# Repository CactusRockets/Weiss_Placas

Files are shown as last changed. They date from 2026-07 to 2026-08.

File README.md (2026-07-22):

# Placa de Iluminação Weiss

Placa de acionamento de iluminação desenvolvida em **KiCad**, responsável por controlar dois LEDs com o objetivo de iluminar a parte interna do weiss através de uma chave (push-button), a partir de uma alimentação externa de **3.3V**. O projeto foi desenhado para ser simples e robusto, priorizando facilidade de montagem (todos os componentes em THT) e baixo custo.

## Visão geral do circuito

O circuito é alimentado externamente via um conector **JST XH de 2 vias**, que entrega +3.3V e GND à placa. Essa alimentação passa por um **push-button (SW1)**, que atua como chave liga/desliga geral do circuito. A partir do botão, a alimentação se divide em **dois ramos em paralelo**, cada um composto por um resistor limitador de corrente em série com um LED de alta potência:

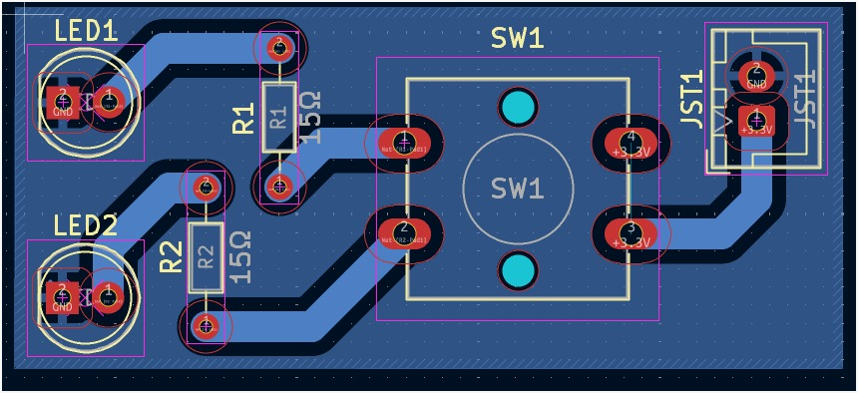
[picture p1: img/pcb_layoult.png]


Ou seja: quando o botão é pressionado (ou travado, dependendo do tipo de chave utilizada), o circuito fecha e os dois LEDs acendem simultaneamente. Cada LED possui seu próprio resistor, de forma que o brilho e a corrente de cada um são definidos de forma independente — isso evita que uma eventual diferença entre os dois LEDs (tensão direta, tolerância) afete o outro ramo, como aconteceria se estivessem em paralelo direto sob um único resistor.

Foram incluídas **PWR_FLAGs** no esquemático em +3.3V e GND. Elas não fazem parte do circuito fisicamente: servem apenas para informar ao ERC (Electrical Rules Checker) do KiCad que esses nós de alimentação são supridos por uma fonte externa (o JST), evitando falsos positivos de "net não alimentada".

## Componentes

| Referência | Componente | Footprint / Símbolo | Função |
|---|---|---|---|
| **JST1** | Conector JST XH 2 vias | `Connector_JST:JST_XH_B2B-XH-A_1x02_P2.50mm_Vertical` | Entrada de alimentação externa (+3.3V e GND) |
| **SW1** | Push-button | `Button_Switch_SMD:SW_SPST_B3S-1000` (footprint na placa: `SW_SPST_Omron_B3F-40xx-CRD`) | Chave de acionamento (liga/desliga) do circuito |
| **R1** | Resistor 15Ω | `Resistor_THT:R_Axial_DIN0204_L3.6mm_D1.6mm_P7.62mm_Horizontal` | Limitador de corrente do LED U1 |
| **R2** | Resistor 15Ω | `Resistor_THT:R_Axial_DIN0204_L3.6mm_D1.6mm_P7.62mm_Horizontal` | Limitador de corrente do LED U2 |
| **U1** | LED de alta potência | `LED_THT:LED_D5.0mm` | Iluminação (ramo 1) |
| **U2** | LED de alta potência | `LED_THT:LED_D5.0mm` | Iluminação (ramo 2) |

> Os símbolos `JST_basic`, `Push_button_4_pin` e `Led_High` são customizados e estão definidos na biblioteca local `CRD_KICAD.kicad_sym`, criada para padronizar os componentes usados nos projetos da Cactus Rockets.

## Funcionamento

O funcionamento da placa é puramente analógico/passivo — não há microcontrolador ou lógica embarcada:

1. A alimentação de +3.3V chega pelo conector **JST1**.
2. O **SW1** atua como interruptor: enquanto estiver fechado, a corrente flui para os dois ramos de LED.
3. Cada ramo (R + LED) limita a corrente que passa pelo respectivo LED, garantindo que ele opere dentro da faixa segura especificada pelo fabricante, evitando queima por excesso de corrente.
4. O retorno de ambos os ramos é feito para o **GND** comum da placa, que fecha o circuito de volta à fonte externa.

Por não haver controle ativo (PWM, microcontrolador, etc.), o brilho dos LEDs é fixo e definido unicamente pelo valor dos resistores e pela tensão de alimentação — não há dimerização nem controle remoto nesta versão da placa.

## Cálculo dos resistores limitadores

O valor do resistor limitador é definido pela equação pela lei de ohm:

```
R = (V_fonte - V_LED) / I_LED
```

Com `V_fonte = 3.3V` e `R = 15Ω`, a corrente em cada ramo depende da tensão direta (V_f) do LED utilizado. Por exemplo:

- Para um LED com V_f ≈ 2.0V → I ≈ (3.3 − 2.0) / 15 ≈ **87 mA**
- Para um LED com V_f ≈ 3.0V → I ≈ (3.3 − 3.0) / 15 ≈ **20 mA**

## Placa (PCB)

- Placa de **1.6mm** de espessura (FR4 padrão), com contorno definido em `Edge.Cuts`.
- Todos os componentes são **THT** (through-hole), facilitando a montagem manual e a soldagem.
- Footprints utilizados:
  - `CRD_Footprints:SW_SPST_Omron_B3F-40xx-CRD` (SW1)
  - `LED_THT:LED_D5.0mm` / `CRD_Footprints:LED_D5.0mm-CRD` (U1, U2)
  - `Resistor_THT:R_Axial_DIN0204_L3.6mm_D1.6mm_P7.62mm_Horizontal` (R1, R2)
  - `Connector_JST:JST_XH_B2B-XH-A_1x02_P2.50mm_Vertical` (JST1)

## Arquivos do projeto

| Arquivo | Descrição |
|---|---|
| `Placa_de_Iluminação_Weiss.kicad_sch` | Esquemático elétrico da placa |
| `Placa_de_Iluminação_Weiss.kicad_pcb` | Layout da placa (PCB) |
| `Placa_de_Iluminação_Weiss.kicad_pro` | Arquivo de projeto do KiCad |
| `CRD_KICAD.kicad_sym` | Biblioteca de símbolos customizados da Cactus Rockets |
| `fp-lib-table` | Tabela de bibliotecas de footprints usadas no projeto |

# Placa de Processamento — Weiss

Placa eletrônica central do projeto **Weiss**, desenvolvida em **KiCad**, responsável por concentrar o processamento, a aquisição de dados, o armazenamento local e as interfaces de telemetria e sinalização do sistema.

O projeto utiliza um **ESP32 DevKit V1** como controlador principal e integra módulos de rádio LoRa, GPS, cartão microSD, barômetro, unidade inercial, buzzer, LED de status e conectores para sinais externos.

> **Atenção:** esta documentação foi levantada a partir do esquemático e do layout da placa. Antes da fabricação ou da integração ao veículo, execute ERC/DRC no KiCad e confira a pinagem com o firmware e com os módulos físicos utilizados.

## Visão geral

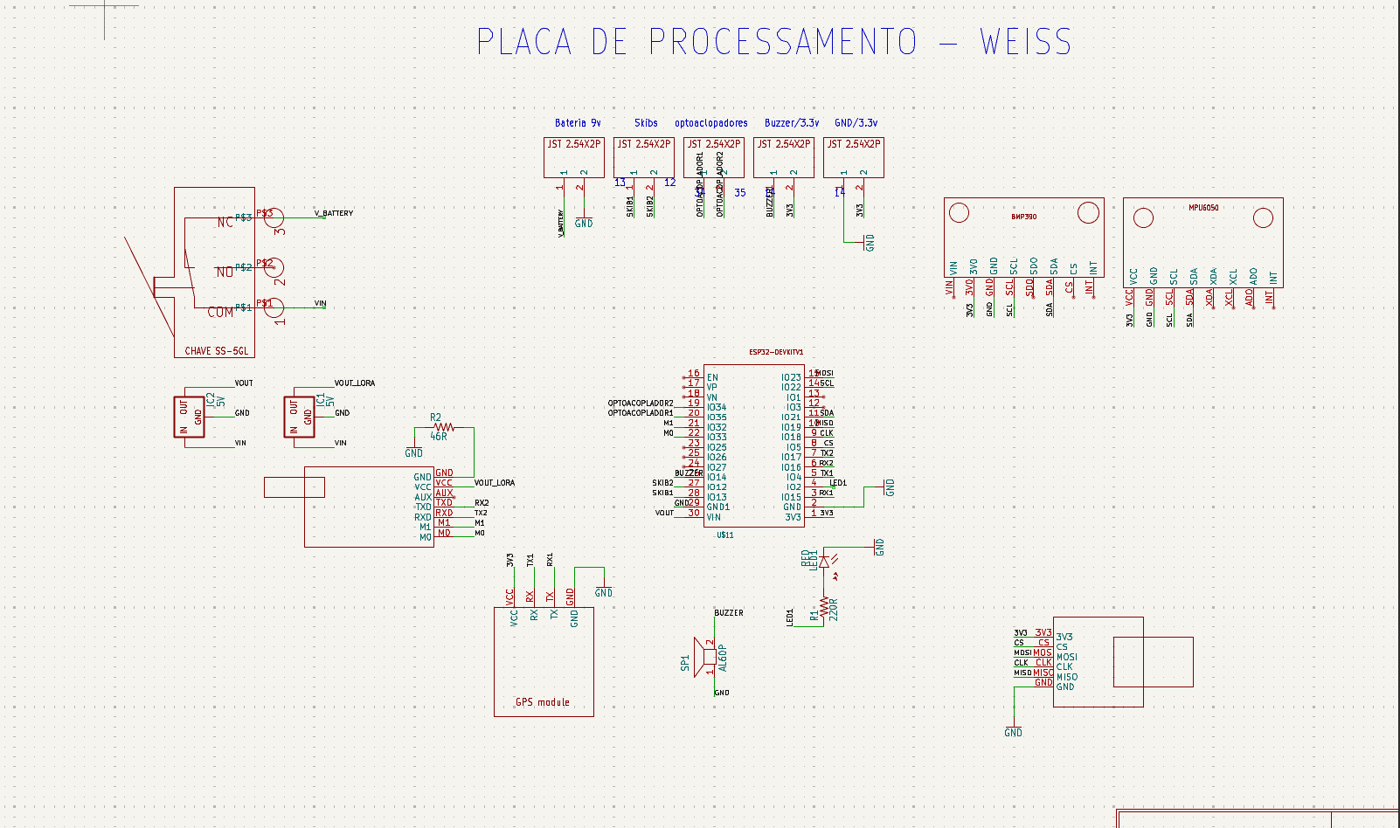
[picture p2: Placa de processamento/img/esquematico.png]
Esquemático da placa de processamento


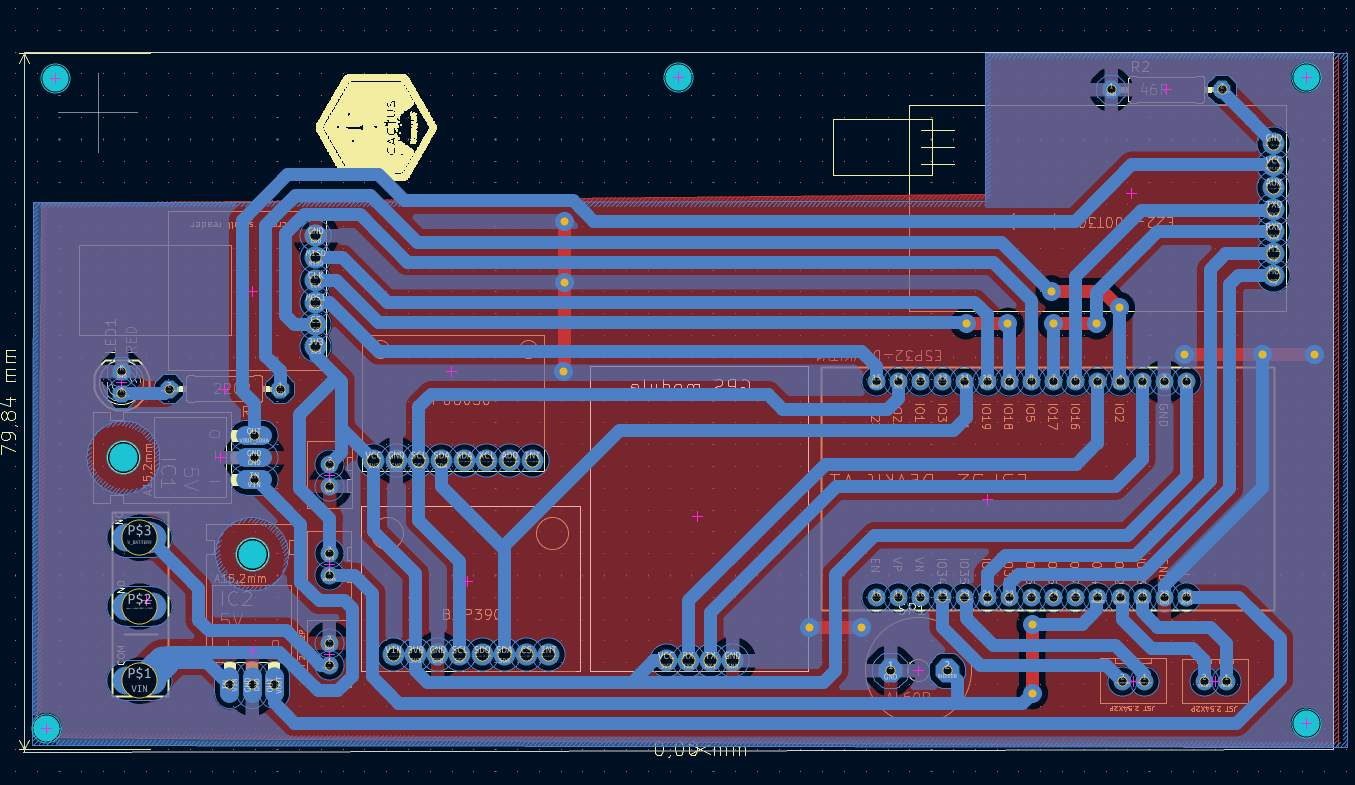
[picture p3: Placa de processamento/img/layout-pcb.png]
Layout da PCB


Principais recursos:

- ESP32 DevKit V1 como unidade de processamento;
- telemetria por módulo LoRa **E22-400T30D**;
- posicionamento por módulo GPS serial;
- registro de dados em cartão microSD via SPI;
- medição de pressão e altitude com **BMP390** via I²C;
- medição inercial com **MPU6050** via I²C;
- buzzer e LED para sinalização local;
- duas entradas provenientes de optoacopladores externos;
- duas linhas de interface identificadas como `SKIB1` e `SKIB2`;
- alimentação por bateria de 9 V, com chave e duas linhas reguladas de 5 V;
- conectores JST de 2 vias para alimentação e sinais auxiliares.

## Arquitetura elétrica

```mermaid
flowchart LR
    B["Bateria 9 V"] --> S["Chave SS-5GL"]
    S --> VIN["VIN"]
    VIN --> R1["Regulador 5 V — VOUT"]
    VIN --> R2["Regulador 5 V — VOUT_LORA"]
    R1 --> ESP["ESP32 DevKit V1"]
    R2 --> LORA["LoRa E22-400T30D"]
    ESP --> V33["Barramento 3,3 V"]
    V33 --> GPS["GPS"]
    V33 --> I2C["BMP390 + MPU6050"]
    V33 --> SD["microSD"]
    ESP <--> LORA
    ESP <--> GPS
    ESP <--> I2C
    ESP <--> SD
```

A chave `U$12` conecta o terminal comum `VIN` ao contato associado a `V_BATTERY`; o outro contato da chave aparece sem conexão no esquemático. A partir de `VIN`, dois reguladores independentes, ambos identificados como **5 V**, geram:

- `VOUT`: alimentação do pino `VIN` do ESP32 DevKit V1;
- `VOUT_LORA`: alimentação dedicada do módulo LoRa.

O barramento de **3,3 V** é distribuído a partir do pino `3V3` do ESP32 para os sensores, GPS, microSD e conectores auxiliares. Todos os subsistemas da placa compartilham o mesmo GND.

## Mapeamento de pinos do ESP32

| GPIO | Rede | Interface / função |
|---:|---|---|
| 2 | `LED1` | LED de status |
| 4 | `TX1` | TX do ESP32 para RX do GPS |
| 5 | `CS` | Chip Select do microSD |
| 12 | `SKIB2` | Linha externa SKIB2 |
| 13 | `SKIB1` | Linha externa SKIB1 |
| 14 | `BUZZER` | Acionamento do buzzer |
| 15 | `RX1` | RX do ESP32 vindo do TX do GPS |
| 16 | `RX2` | RX do ESP32 vindo do TXD do LoRa |
| 17 | `TX2` | TX do ESP32 para RXD do LoRa |
| 18 | `CLK` | Clock SPI do microSD |
| 19 | `MISO` | Dados SPI do microSD para o ESP32 |
| 21 | `SDA` | Dados do barramento I²C |
| 22 | `SCL` | Clock do barramento I²C |
| 23 | `MOSI` | Dados SPI do ESP32 para o microSD |
| 32 | `M1` | Seleção de modo do LoRa |
| 33 | `M0` | Seleção de modo do LoRa |
| 34 | `OPTOACOPLADOR2` | Entrada externa isolada |
| 35 | `OPTOACOPLADOR1` | Entrada externa isolada |

> Os GPIOs 34 e 35 do ESP32 são somente de entrada. As linhas `SKIB1` e `SKIB2` chegam diretamente ao ESP32 no esquema apresentado; elas são sinais lógicos e **não devem acionar cargas pirotécnicas diretamente**. Qualquer carga desse tipo exige estágio externo de potência, intertravamentos e isolamento apropriados.

## Interfaces dos módulos

### LoRa E22-400T30D

| Pino do módulo | Rede da placa | Destino |
|---|---|---|
| `VCC` | `VOUT_LORA` | Alimentação dedicada de 5 V |
| `GND` | `GND` | Referência comum |
| `TXD` | `RX2` | GPIO16 do ESP32 |
| `RXD` | `TX2` | GPIO17 do ESP32 |
| `M0` | `M0` | GPIO33 do ESP32 |
| `M1` | `M1` | GPIO32 do ESP32 |
| `AUX` | Sem conexão | Reservado no layout atual |

### GPS

| Pino do módulo | Rede da placa | Destino |
|---|---|---|
| `VCC` | `3V3` | Alimentação de 3,3 V |
| `GND` | `GND` | Referência comum |
| `RX` | `TX1` | GPIO4 do ESP32 |
| `TX` | `RX1` | GPIO15 do ESP32 |

### BMP390 e MPU6050

Os dois sensores compartilham o barramento I²C:

| Sinal | GPIO do ESP32 | Módulos |
|---|---:|---|
| `SDA` | 21 | BMP390 e MPU6050 |
| `SCL` | 22 | BMP390 e MPU6050 |
| `3V3` | — | Alimentação |
| `GND` | — | Referência comum |

No layout atual, os pinos auxiliares `CS`, `SDO` e `INT` do BMP390 e `XDA`, `XCL`, `ADO` e `INT` do MPU6050 não são utilizados.

### Cartão microSD

| Sinal | GPIO do ESP32 |
|---|---:|
| `CS` | 5 |
| `CLK` | 18 |
| `MISO` | 19 |
| `MOSI` | 23 |
| `VCC` | 3,3 V |
| `GND` | GND |

## Conectores auxiliares

| Referência | Identificação | Pino 1 | Pino 2 |
|---|---|---|---|
| `U$10` | Bateria 9 V | `V_BATTERY` | `GND` |
| `U$6` | Skibs | `SKIB1` | `SKIB2` |
| `U$7` | Optoacopladores | `OPTOACOPLADOR1` | `OPTOACOPLADOR2` |
| `U$4` | Buzzer / 3,3 V | `BUZZER` | `3V3` |
| `U$5` | GND / 3,3 V | `3V3` | `GND` |

## Componentes principais

| Referência | Componente | Função |
|---|---|---|
| `U$11` | ESP32 DevKit V1 | Processamento e controle das interfaces |
| `U$2` | E22-400T30D | Comunicação LoRa |
| `U$3` | GPS Module | Posicionamento e referência de tempo |
| `U$1` | BMP390 | Pressão atmosférica e altitude |
| `U$9` | MPU6050 | Acelerômetro e giroscópio |
| `U$8` | MicroSD Small Reader | Armazenamento local de dados |
| `IC1` | Regulador 5 V | Alimentação `VOUT` do ESP32 |
| `IC2` | Regulador 5 V | Alimentação `VOUT_LORA` |
| `U$12` | Chave SS-5GL | Comutação da alimentação de entrada |
| `SP1` | AL60P | Buzzer |
| `LED1` | LED vermelho 5 mm | Indicação visual |
| `R1` | 220 Ω | Limitação de corrente do LED |
| `R2` | 46 Ω | Componente auxiliar; o pad 2 está sem conexão funcional no layout atual |
| `U$4` a `U$7`, `U$10` | JST 2,54 mm, 2 vias | Alimentação e sinais externos |

## Dimensões e construção da PCB

- dimensões aproximadas do contorno: **150 × 80 mm**;
- espessura configurada: **1,6 mm**;
- placa de duas camadas de cobre (`F.Cu` e `B.Cu`);
- componentes predominantemente THT e módulos montados por barras de pinos;
- planos de cobre e trilhas de alimentação de maior largura;
- footprints personalizados disponíveis na biblioteca local `Weiss.pretty`.

## Arquivos do projeto

| Caminho | Descrição |
|---|---|
| `Esquema.kicad_pro` | Projeto principal do KiCad |
| `Esquema.kicad_sch` | Esquemático elétrico |
| `Esquema.kicad_pcb` | Layout da PCB |
| `Esquema.svg` | Exportação vetorial do esquemático |
| `Esquema.kicad_dru` | Regras personalizadas da placa |
| `Weiss.pretty/` | Biblioteca local de footprints |
| `BibliotecasCRD-KiCad-main/` | Bibliotecas auxiliares utilizadas pelo projeto |
| `fp-lib-table` | Tabela de bibliotecas de footprints |
| `sym-lib-table` | Tabela de bibliotecas de símbolos |

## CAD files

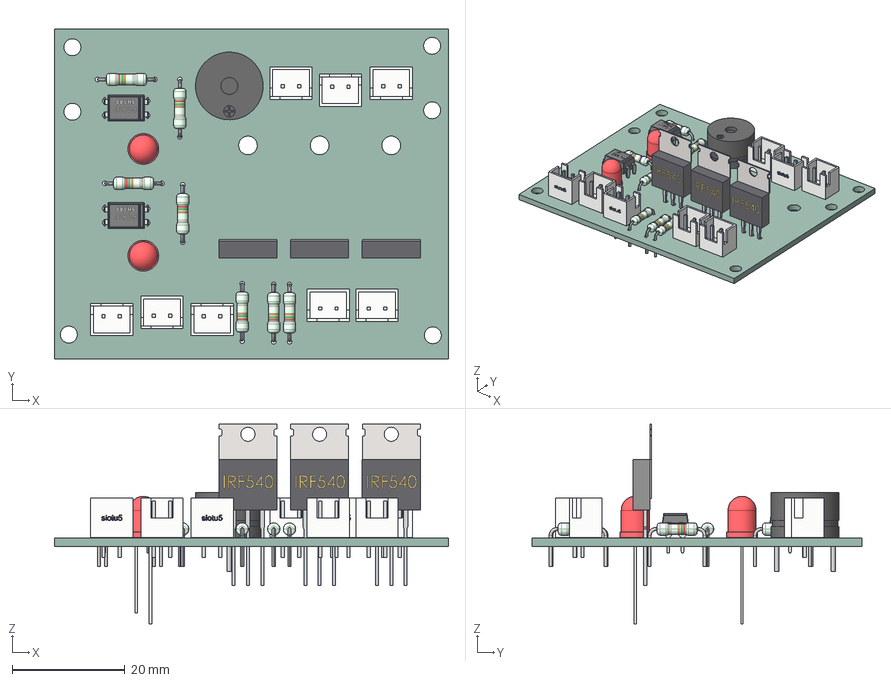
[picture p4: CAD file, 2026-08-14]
placa_de_acionamento_weiss/placa_acionamento_weiss_versao3/acionamento 3d.step
69.8 x 58.5 x 35.4 mm
Resistor x 7
Bileşen1 x 8
Bileşen2 x 8
Bileşen3 x 8
(Unsaved) x 3
User Library-DIP4-7.62-2.54 x 2
LED 3mm (Red) v3 x 2
Buzzer v1
Esquema_PCB

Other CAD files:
placa_de_acionamento_weiss/placa_acionamento_weiss_versao3/Placa de Acionamento 3D - Weiss.f3d

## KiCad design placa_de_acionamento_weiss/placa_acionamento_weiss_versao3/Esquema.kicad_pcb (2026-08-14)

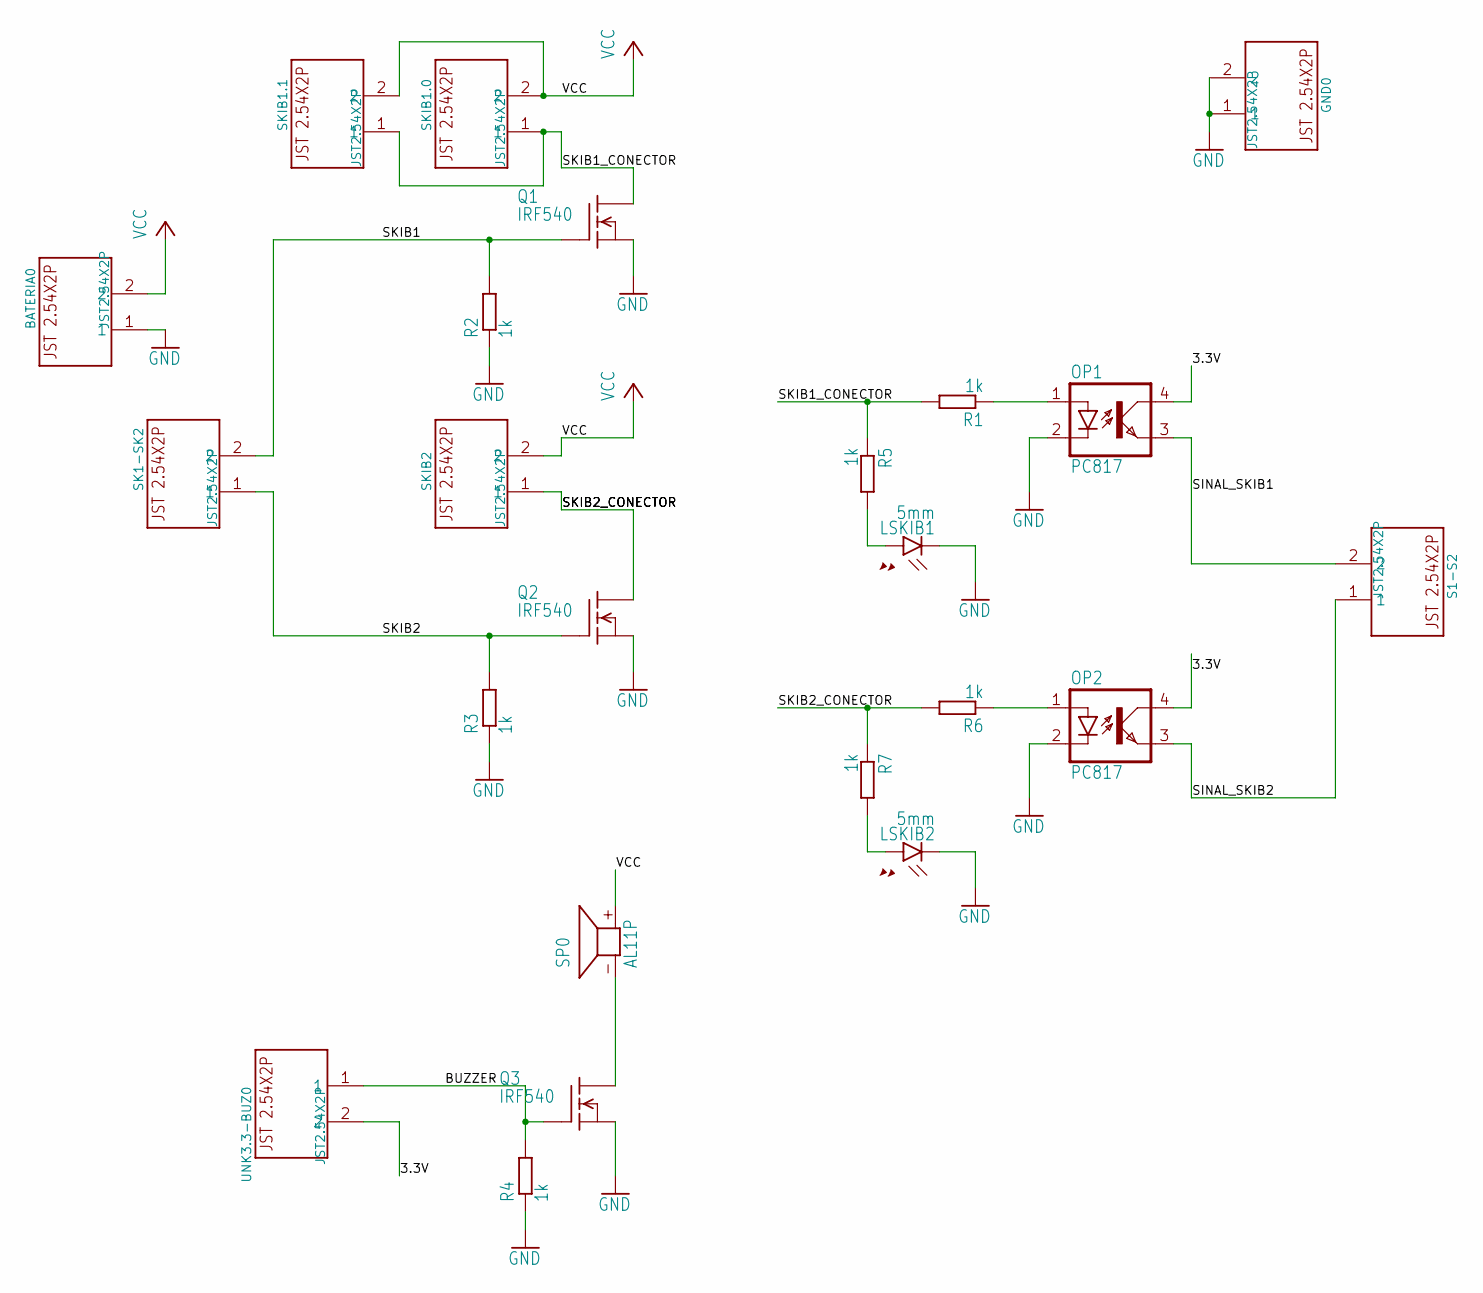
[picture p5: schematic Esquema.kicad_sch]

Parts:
BATERIA0: JST2.54X2P; JST2.54X2P_FOOTPRINT
GND0: JST2.54X2P; JST2.54X2P_FOOTPRINT
LSKIB1, LSKIB2: 5mm; LED5MM
OP1, OP2: PC817; DIL04
Q1, Q2, Q3: IRF540; TO220
R1, R2, R3, R4, R5, R6, R7: 1k; 0207_10
S1-S2: JST2.54X2P; JST2.54X2P_FOOTPRINT
SK1-SK2: JST2.54X2P; JST2.54X2P_FOOTPRINT
SKIB1.0, SKIB1.1, SKIB2: JST2.54X2P; JST2.54X2P_FOOTPRINT
SP0: AL11P
UNK3.3-BUZ0: JST2.54X2P; JST2.54X2P_FOOTPRINT

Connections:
3.3V: OP1.4 (COL), OP2.4 (COL), UNK3.3-BUZ0.2
BUZZER: Q3.1 (G), R4.2, UNK3.3-BUZ0.1
GND: BATERIA0.1, GND0.1, GND0.2, LSKIB1.K (C), LSKIB2.K (C), OP1.2 (C), OP2.2 (C), Q1.3 (S), Q2.3 (S), Q3.3 (S), R2.1, R3.1, R4.1
unnamed: LSKIB2.A, R7.2
unnamed: Q3.2 (D), SP0.- (1)
unnamed: LSKIB1.A, R5.2
unnamed: OP1.1 (A), R1.1
unnamed: OP2.1 (A), R6.1
SINAL_SKIB1: OP1.3 (EMIT), S1-S2.2
SINAL_SKIB2: OP2.3 (EMIT), S1-S2.1
SKIB1: Q1.1 (G), R2.2, SK1-SK2.2
SKIB1_CONECTOR: Q1.2 (D), R1.2, R5.1, SKIB1.0.1, SKIB1.1.1
SKIB2: Q2.1 (G), R3.2, SK1-SK2.1
SKIB2_CONECTOR: Q2.2 (D), R6.2, R7.1, SKIB2.1
VCC: BATERIA0.2, SKIB1.0.2, SKIB1.1.2, SKIB2.2, SP0.+ (2)

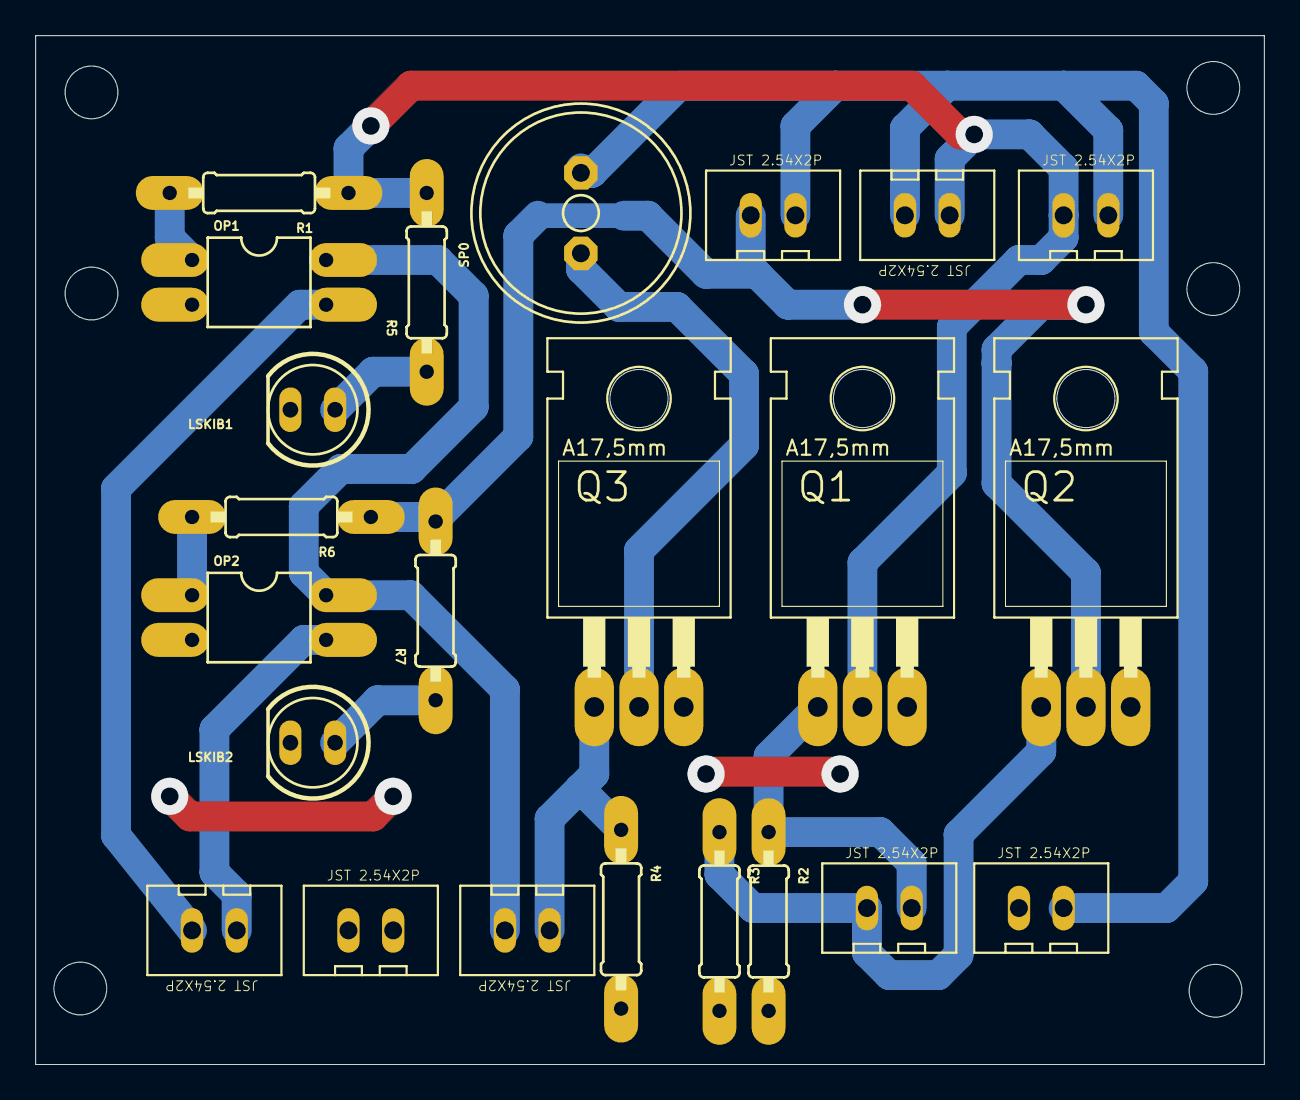
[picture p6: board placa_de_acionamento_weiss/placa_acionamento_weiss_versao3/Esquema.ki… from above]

Board: 2 copper layers, 69.8 x 58.5 mm, 29 parts (0 on the bottom side), 15 nets.

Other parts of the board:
UNK_HOLE_0: dummyfp0
UNK_HOLE_1: dummyfp1
UNK_HOLE_2: dummyfp2
UNK_HOLE_3: dummyfp3
UNK_HOLE_4: dummyfp4
UNK_HOLE_5: dummyfp5

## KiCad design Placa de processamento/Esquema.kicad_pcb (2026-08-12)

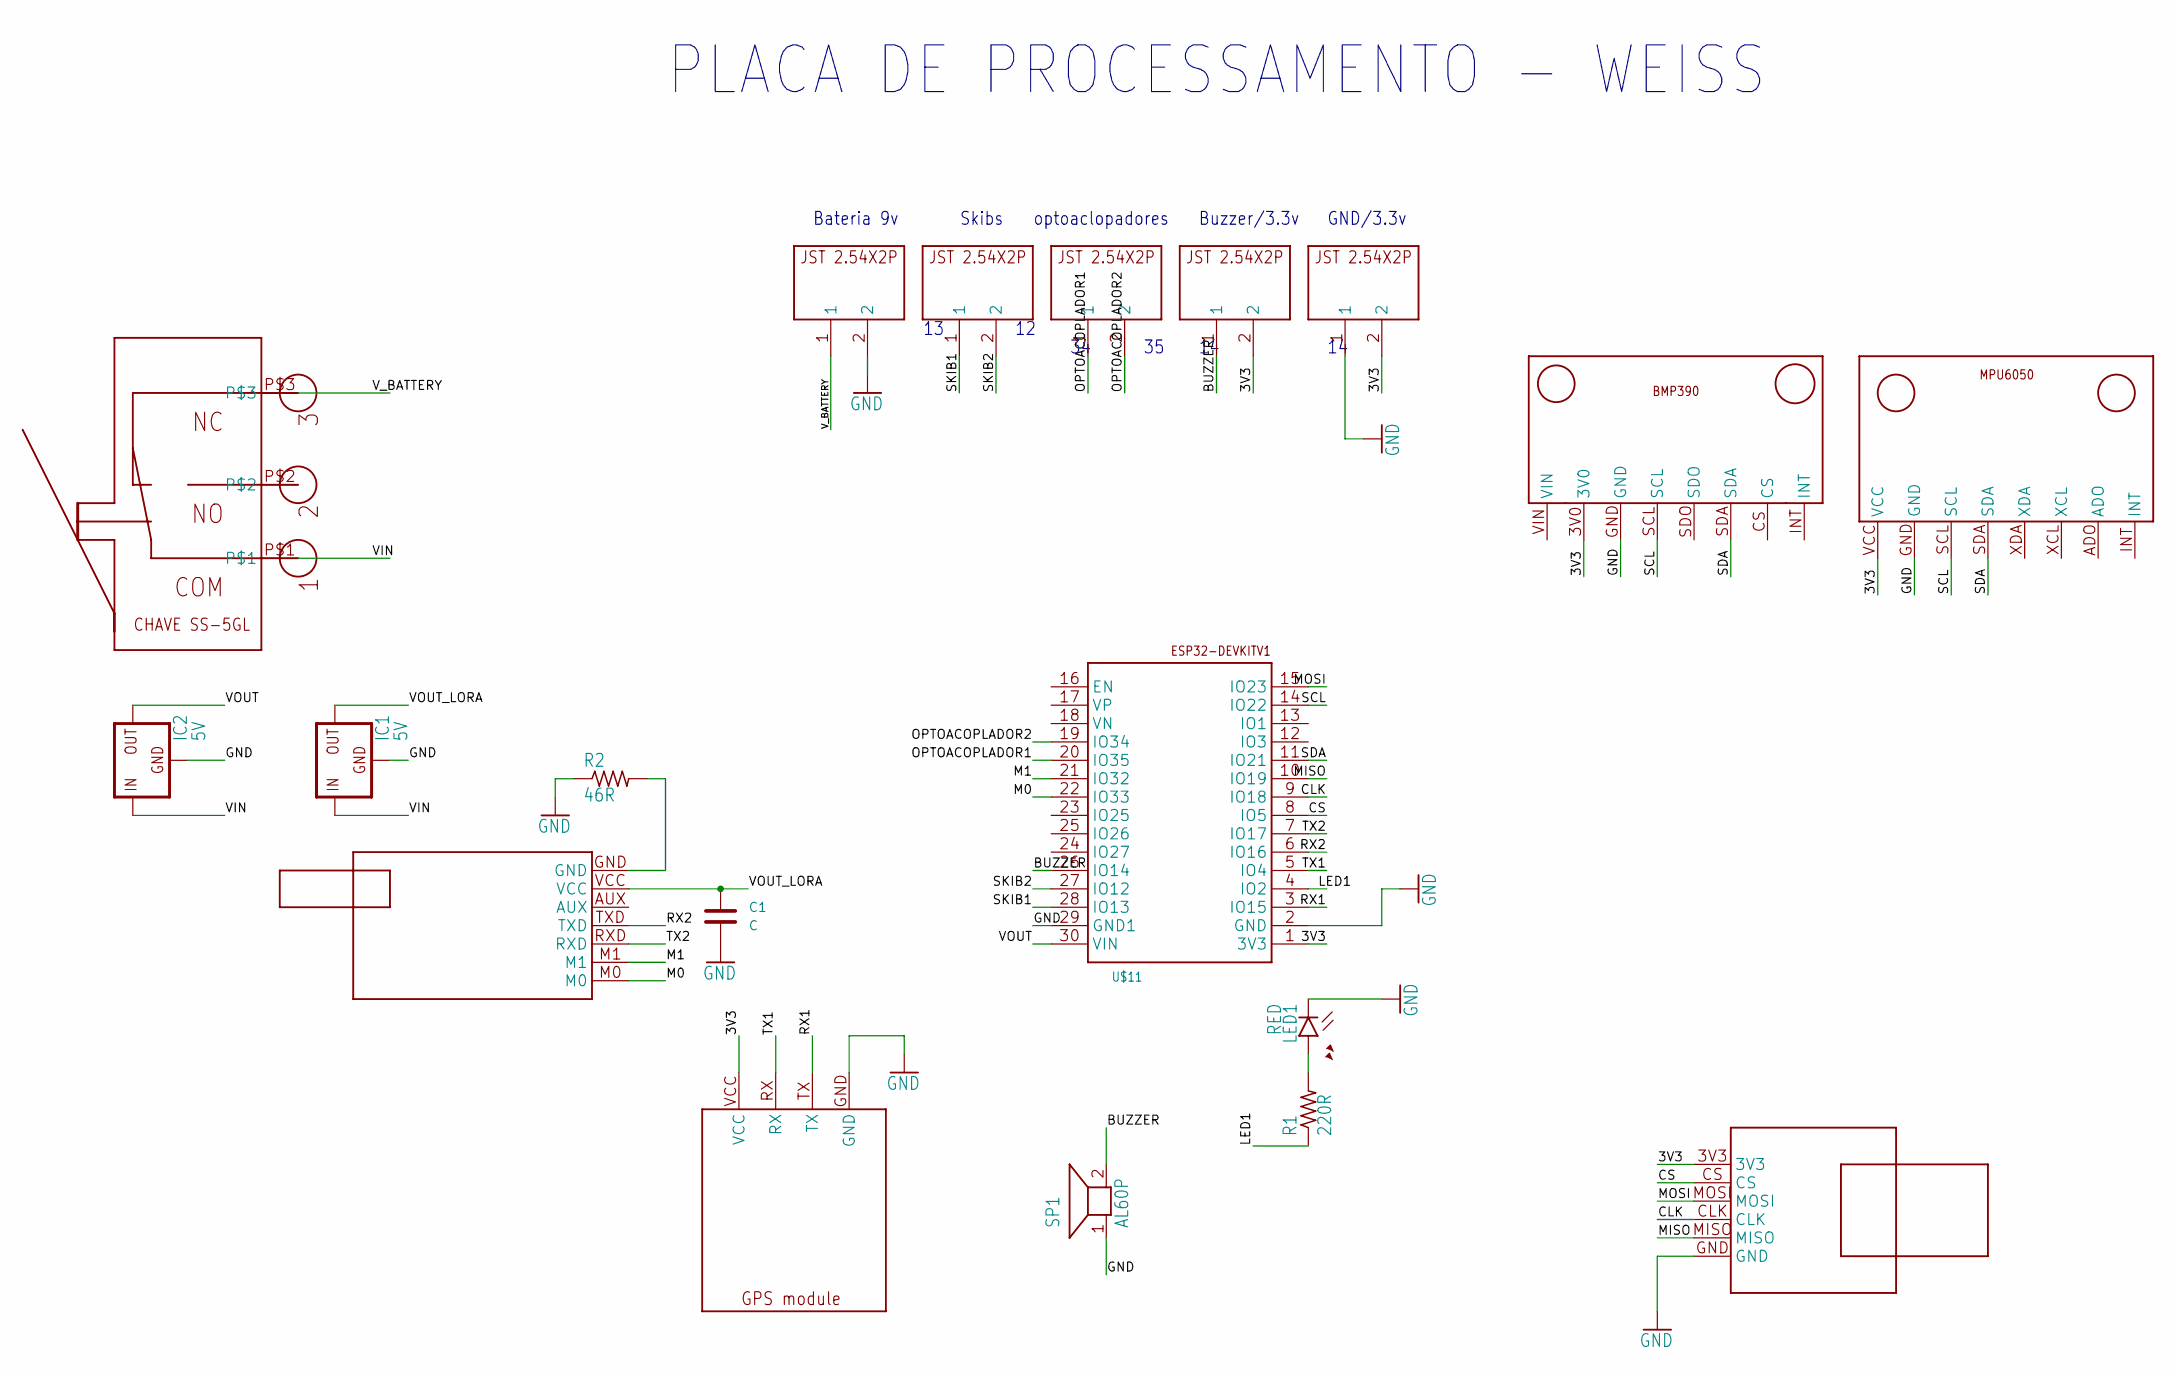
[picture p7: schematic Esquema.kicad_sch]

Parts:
C1: C
IC1, IC2: 5V; 78XXL
LED1: RED; LED5MM
R1: 220R; 0309_12
R2: 46R; 0309_12
SP1: AL60P
U$1: BMP390V1; BMP390_FOOTPRINT
U$2: E22-400T30D; E22-400T30D_FOOTPRINT
U$3: GPS_MODULE; GPS_MODULE_FOOTPRINT
U$4, U$5, U$6, U$7: JST2.54X2P; JST2.54X2P_FOOTPRINT
U$8: MICROSD_SMALL_READER; MICROSD_SMALL_READER_FOOTPRINT
U$9: MPU6050V1; MPU6050_FOOTPRINT
U$10: JST2.54X2P; JST2.54X2P_FOOTPRINT_39051337
U$11: ESP32DEVKITV1; ESP32-DEVKITV1
U$12: CHAVE_SS-5GL; CHAVESS-5GL

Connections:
/3V3: U$1.3V0, U$3.VCC, U$4.2, U$8.3V3, U$9.VCC, U$10.2, U$11.1 (3V3)
/BUZZER: SP1.2, U$4.1, U$11.26 (IO14)
/CLK: U$8.CLK, U$11.9 (IO18)
/CS: U$8.CS, U$11.8 (IO5)
/LED1: R1.1, U$11.4 (IO2)
/M0: U$2.M0, U$11.22 (IO33)
/M1: U$2.M1, U$11.21 (IO32)
/MISO: U$8.MISO, U$11.10 (IO19)
/MOSI: U$8.MOSI, U$11.15 (IO23)
/OPTOACOPLADOR1: U$5.1, U$11.20 (IO35)
/OPTOACOPLADOR2: U$5.2, U$11.19 (IO34)
/RX1: U$3.TX, U$11.3 (IO15)
/RX2: U$2.TXD, U$11.6 (IO16)
/SCL: U$1.SCL, U$9.SCL, U$11.14 (IO22)
/SDA: U$1.SDA, U$9.SDA, U$11.11 (IO21)
/SKIB1: U$6.1, U$11.28 (IO13)
/SKIB2: U$6.2, U$11.27 (IO12)
/TX1: U$3.RX, U$11.5 (IO4)
/TX2: U$2.RXD, U$11.7 (IO17)
/VIN: IC1.IN, IC2.IN, U$12.P$1
/VOUT: IC2.OUT, U$11.30 (VIN)
/VOUT_LORA: C1.1, IC1.OUT, U$2.VCC
/V_BATTERY: U$7.1, U$12.P$3
GND: C1.2, IC1.GND, IC2.GND, LED1.K (C), R2.1, SP1.1, U$1.GND, U$3.GND, U$7.2, U$8.GND, U$9.GND, U$10.1, U$11.2 (GND), U$11.29 (GND1)
unnamed: LED1.A, R1.2
unnamed: R2.2, U$2.GND

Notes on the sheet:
Bateria 9v
PLACA DE PROCESSAMENTO - WEISS
Skibs
GND/3.3v
Buzzer/3.3v
optoaclopadores

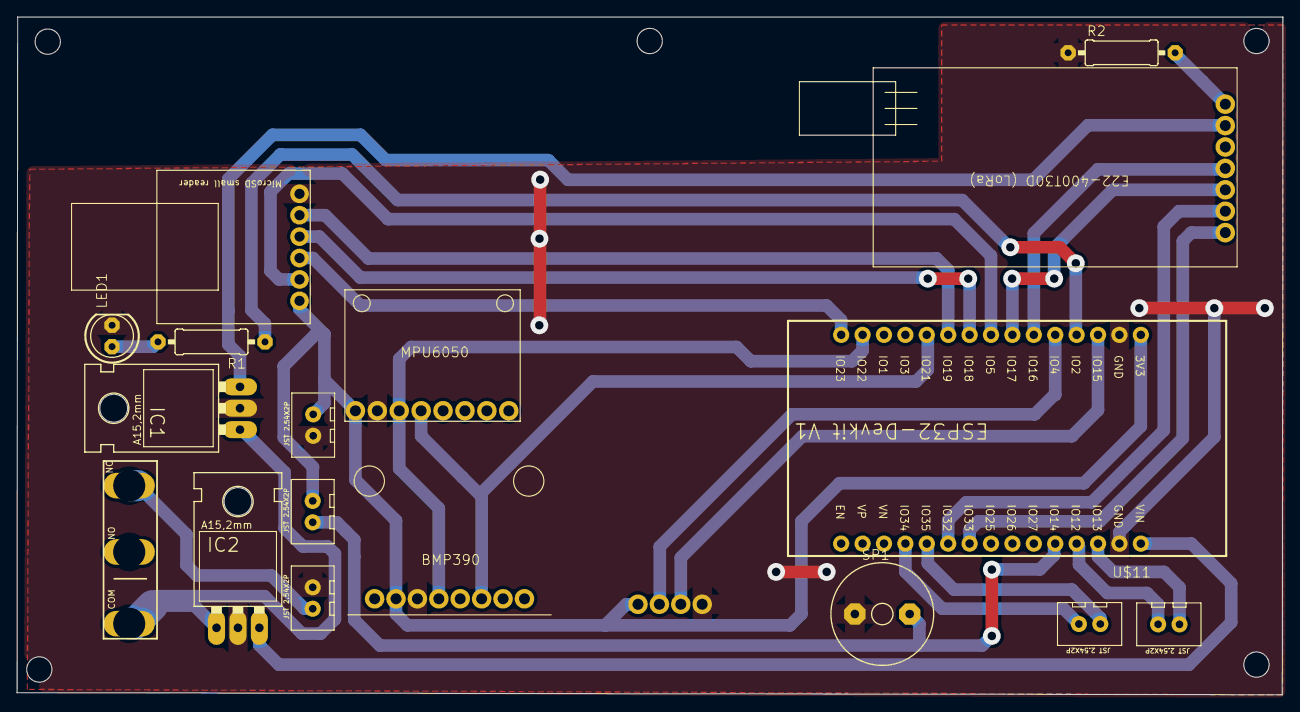
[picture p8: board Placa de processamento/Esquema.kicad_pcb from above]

Board: 2 copper layers, 150.2 x 80.4 mm, 23 parts (1 on the bottom side), 26 nets.

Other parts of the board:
UNK_HOLE_0: dummyfp0
UNK_HOLE_1: dummyfp1
UNK_HOLE_2: dummyfp2
UNK_HOLE_3: dummyfp3
UNK_HOLE_4: dummyfp4

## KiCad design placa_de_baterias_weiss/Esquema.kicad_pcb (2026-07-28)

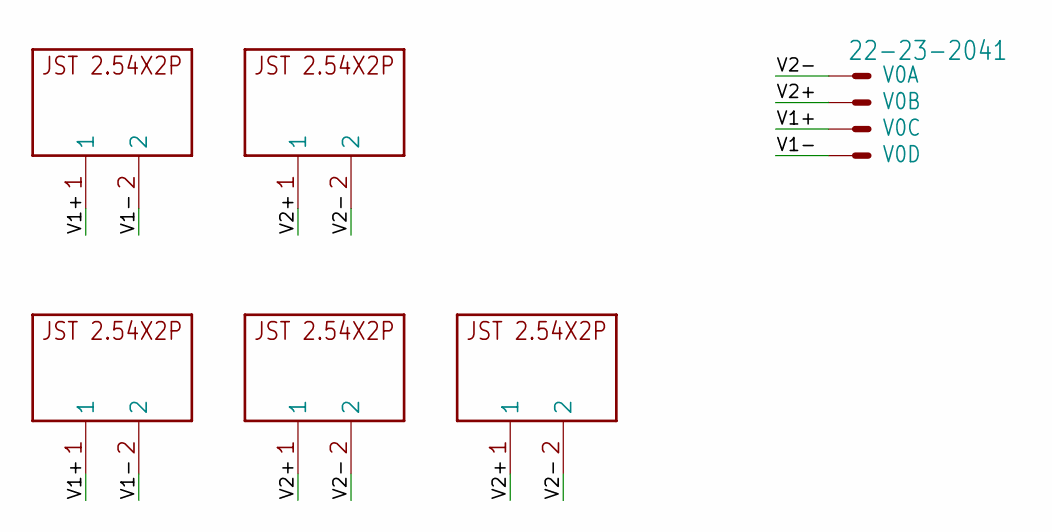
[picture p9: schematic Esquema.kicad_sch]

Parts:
U$1, U$2, U$3, U$4, U$5: JST2.54X2P; JST2.54X2P_FOOTPRINT
V0: 22-23-2041

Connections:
V1+: U$1.1, U$4.1, V0.3
V1-: U$1.2, U$4.2, V0.4
V2+: U$2.1, U$3.1, U$5.1, V0.2
V2-: U$2.2, U$3.2, U$5.2, V0.1

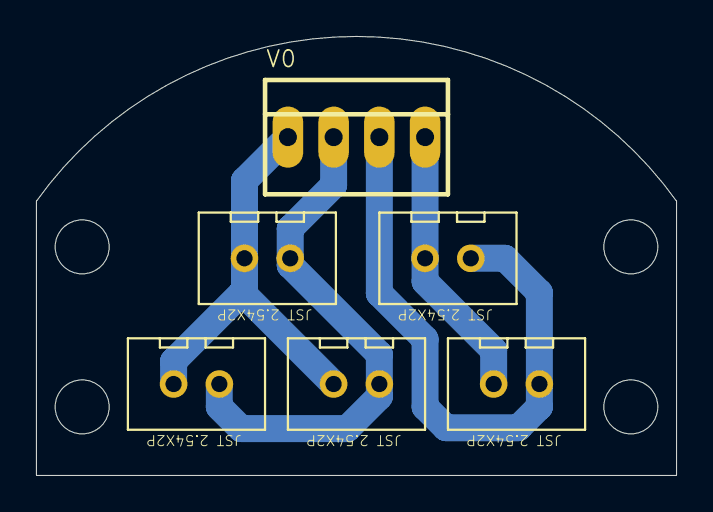
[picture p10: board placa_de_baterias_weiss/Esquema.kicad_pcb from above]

Board: 2 copper layers, 35.6 x 24.4 mm, 10 parts (0 on the bottom side), 4 nets.

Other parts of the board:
UNK_HOLE_0: dummyfp0
UNK_HOLE_1: dummyfp1
UNK_HOLE_2: dummyfp2
UNK_HOLE_3: dummyfp3

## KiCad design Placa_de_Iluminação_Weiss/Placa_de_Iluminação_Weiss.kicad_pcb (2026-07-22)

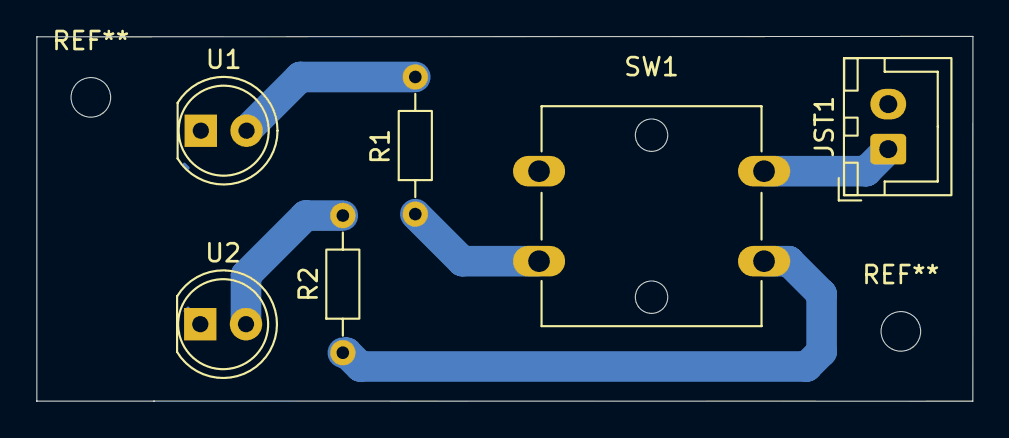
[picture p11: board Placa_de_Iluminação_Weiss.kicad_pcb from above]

Board: 2 copper layers, 52.0 x 20.3 mm, 6 parts (0 on the bottom side), 6 nets.

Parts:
JST1: JST_XH_B2B-XH-A_1x02_P2.50mm_Vertical
R1, R2: 15Ω; R_Axial_DIN0204_L3.6mm_D1.6mm_P7.62mm_Horizontal
SW1: SW_SPST_Omron_B3F-40xx-CRD
U1, U2: LED_D5.0mm-CRD

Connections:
+3.3V: JST1.1 (3.3v), SW1.4 (A)
GND: JST1.2 (GND), U1.2, U2.2
unnamed: R1.1, SW1.2
unnamed: R1.2, U1.1
unnamed: R2.2, U2.1
unnamed: R2.1, SW1.3 (K)

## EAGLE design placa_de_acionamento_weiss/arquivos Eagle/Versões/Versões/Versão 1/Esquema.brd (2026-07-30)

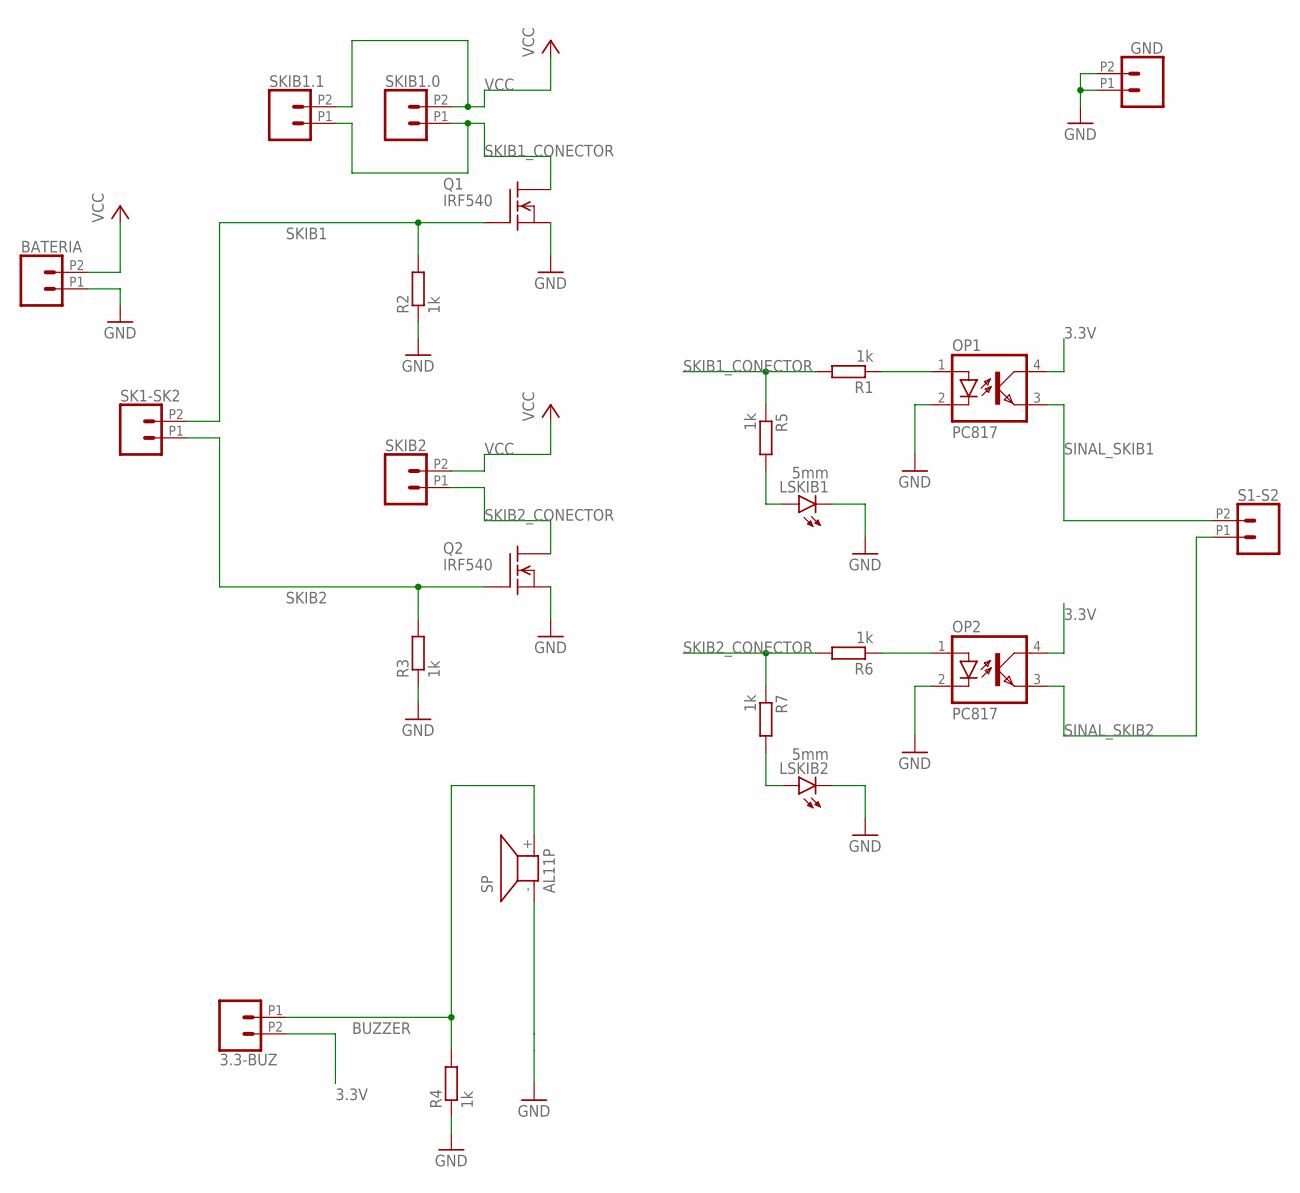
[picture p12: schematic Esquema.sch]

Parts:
3.3-BUZ: CONN_022.54MM_SCREWTERM; 1X02_2.54_SCREWTERM
BATERIA: CONN_022.54MM_SCREWTERM; 1X02_2.54_SCREWTERM
GND: CONN_022.54MM_SCREWTERM; 1X02_2.54_SCREWTERM
LSKIB1, LSKIB2: 5mm; LED5MM
OP1, OP2: PC817; DIL04
Q1, Q2: IRF540; TO220
R1, R2, R3, R4, R5, R6, R7: 1k; 0207/10
S1-S2: CONN_022.54MM_SCREWTERM; 1X02_2.54_SCREWTERM
SK1-SK2: CONN_022.54MM_SCREWTERM; 1X02_2.54_SCREWTERM
SKIB1.0, SKIB1.1, SKIB2: CONN_022.54MM_SCREWTERM; 1X02_2.54_SCREWTERM
SP: AL11P

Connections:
3.3V: 3.3-BUZ.P2 (2), OP1.4 (COL), OP2.4 (COL)
BUZZER: 3.3-BUZ.P1 (1), R4.2, SP.+ (2)
GND: BATERIA.P1 (1), GND.P1 (1), GND.P2 (2), LSKIB1.K (C), LSKIB2.K (C), OP1.2 (C), OP2.2 (C), Q1.3 (S), Q2.3 (S), R2.1, R3.1, R4.1, SP.- (1)
unnamed: LSKIB2.A, R7.2
unnamed: LSKIB1.A, R5.2
unnamed: OP1.1 (A), R1.1
unnamed: OP2.1 (A), R6.1
SINAL_SKIB1: OP1.3 (EMIT), S1-S2.P2 (2)
SINAL_SKIB2: OP2.3 (EMIT), S1-S2.P1 (1)
SKIB1: Q1.1 (G), R2.2, SK1-SK2.P2 (2)
SKIB1_CONECTOR: Q1.2 (D), R1.2, R5.1, SKIB1.0.P1 (1), SKIB1.1.P1 (1)
SKIB2: Q2.1 (G), R3.2, SK1-SK2.P1 (1)
SKIB2_CONECTOR: Q2.2 (D), R6.2, R7.1, SKIB2.P1 (1)
VCC: BATERIA.P2 (2), SKIB1.0.P2 (2), SKIB1.1.P2 (2), SKIB2.P2 (2)

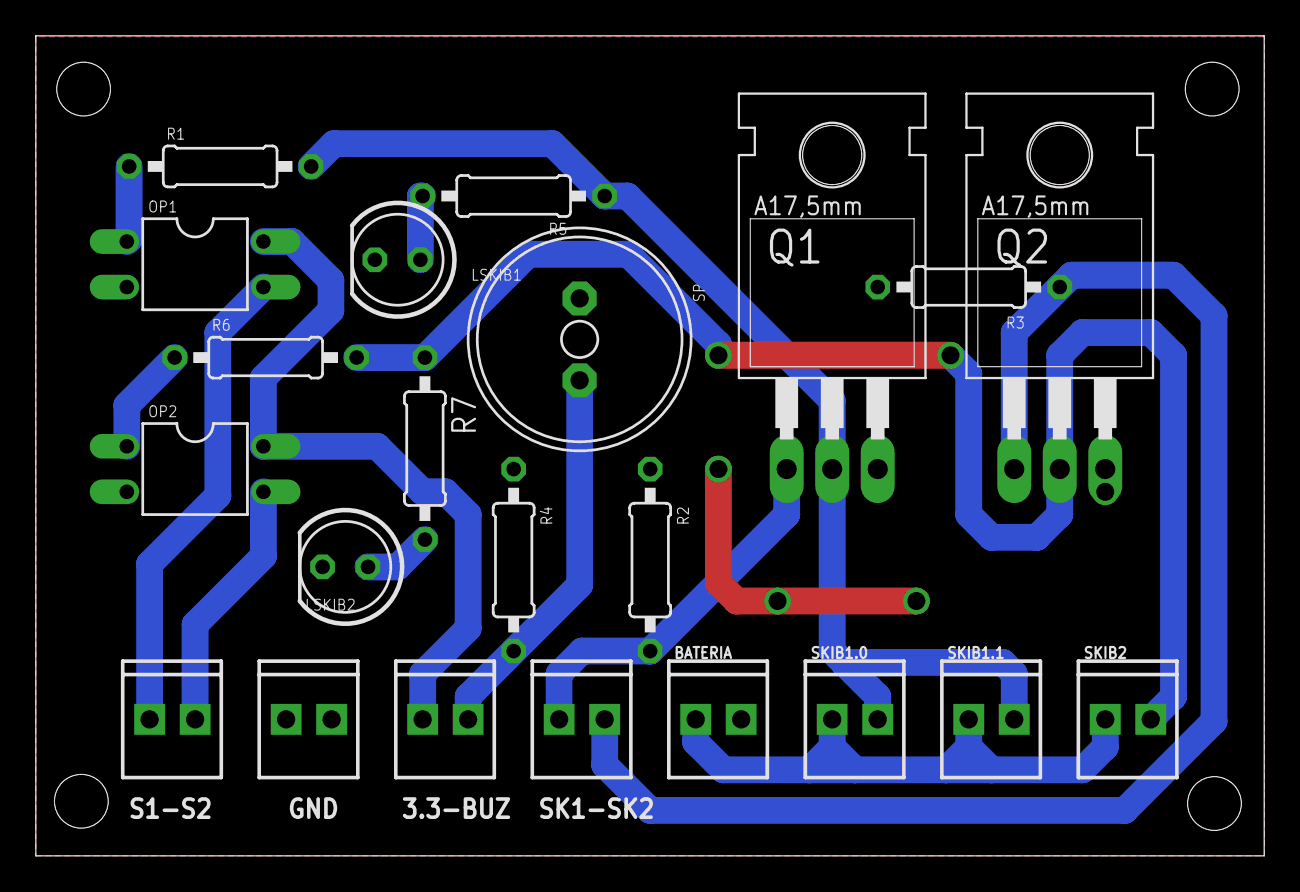
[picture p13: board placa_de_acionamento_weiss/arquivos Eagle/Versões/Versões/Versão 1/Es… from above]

Board: 2 copper layers, 68.6 x 45.8 mm, 22 parts (0 on the bottom side), 14 nets.

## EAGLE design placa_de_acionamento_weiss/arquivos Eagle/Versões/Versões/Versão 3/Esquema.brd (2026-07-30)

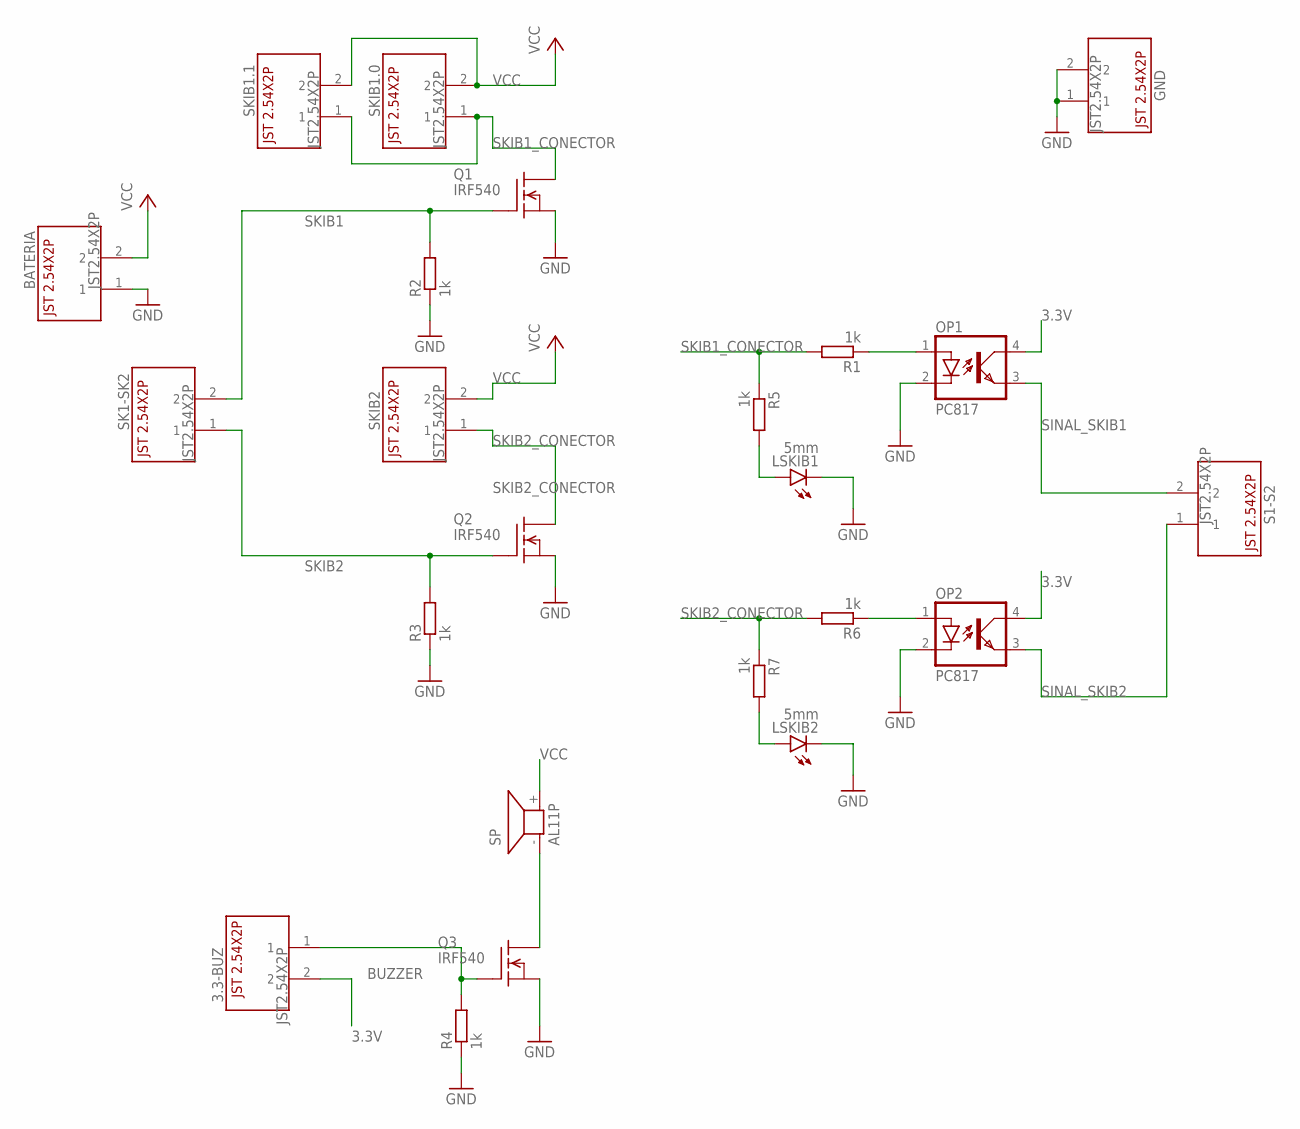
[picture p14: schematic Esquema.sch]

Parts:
3.3-BUZ: JST2.54X2P; JST2.54X2P_FOOTPRINT
BATERIA: JST2.54X2P; JST2.54X2P_FOOTPRINT
GND: JST2.54X2P; JST2.54X2P_FOOTPRINT
LSKIB1, LSKIB2: 5mm; LED5MM
OP1, OP2: PC817; DIL04
Q1, Q2, Q3: IRF540; TO220
R1, R2, R3, R4, R5, R6, R7: 1k; 0207/10
S1-S2: JST2.54X2P; JST2.54X2P_FOOTPRINT
SK1-SK2: JST2.54X2P; JST2.54X2P_FOOTPRINT
SKIB1.0, SKIB1.1, SKIB2: JST2.54X2P; JST2.54X2P_FOOTPRINT
SP: AL11P

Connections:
3.3V: 3.3-BUZ.2, OP1.4 (COL), OP2.4 (COL)
BUZZER: 3.3-BUZ.1, Q3.1 (G), R4.2
GND: BATERIA.1, GND.1, GND.2, LSKIB1.K (C), LSKIB2.K (C), OP1.2 (C), OP2.2 (C), Q1.3 (S), Q2.3 (S), Q3.3 (S), R2.1, R3.1, R4.1
unnamed: LSKIB2.A, R7.2
unnamed: Q3.2 (D), SP.- (1)
unnamed: LSKIB1.A, R5.2
unnamed: OP1.1 (A), R1.1
unnamed: OP2.1 (A), R6.1
SINAL_SKIB1: OP1.3 (EMIT), S1-S2.2
SINAL_SKIB2: OP2.3 (EMIT), S1-S2.1
SKIB1: Q1.1 (G), R2.2, SK1-SK2.2
SKIB1_CONECTOR: Q1.2 (D), R1.2, R5.1, SKIB1.0.1, SKIB1.1.1
SKIB2: Q2.1 (G), R3.2, SK1-SK2.1
SKIB2_CONECTOR: Q2.2 (D), R6.2, R7.1, SKIB2.1
VCC: BATERIA.2, SKIB1.0.2, SKIB1.1.2, SKIB2.2, SP.+ (2)

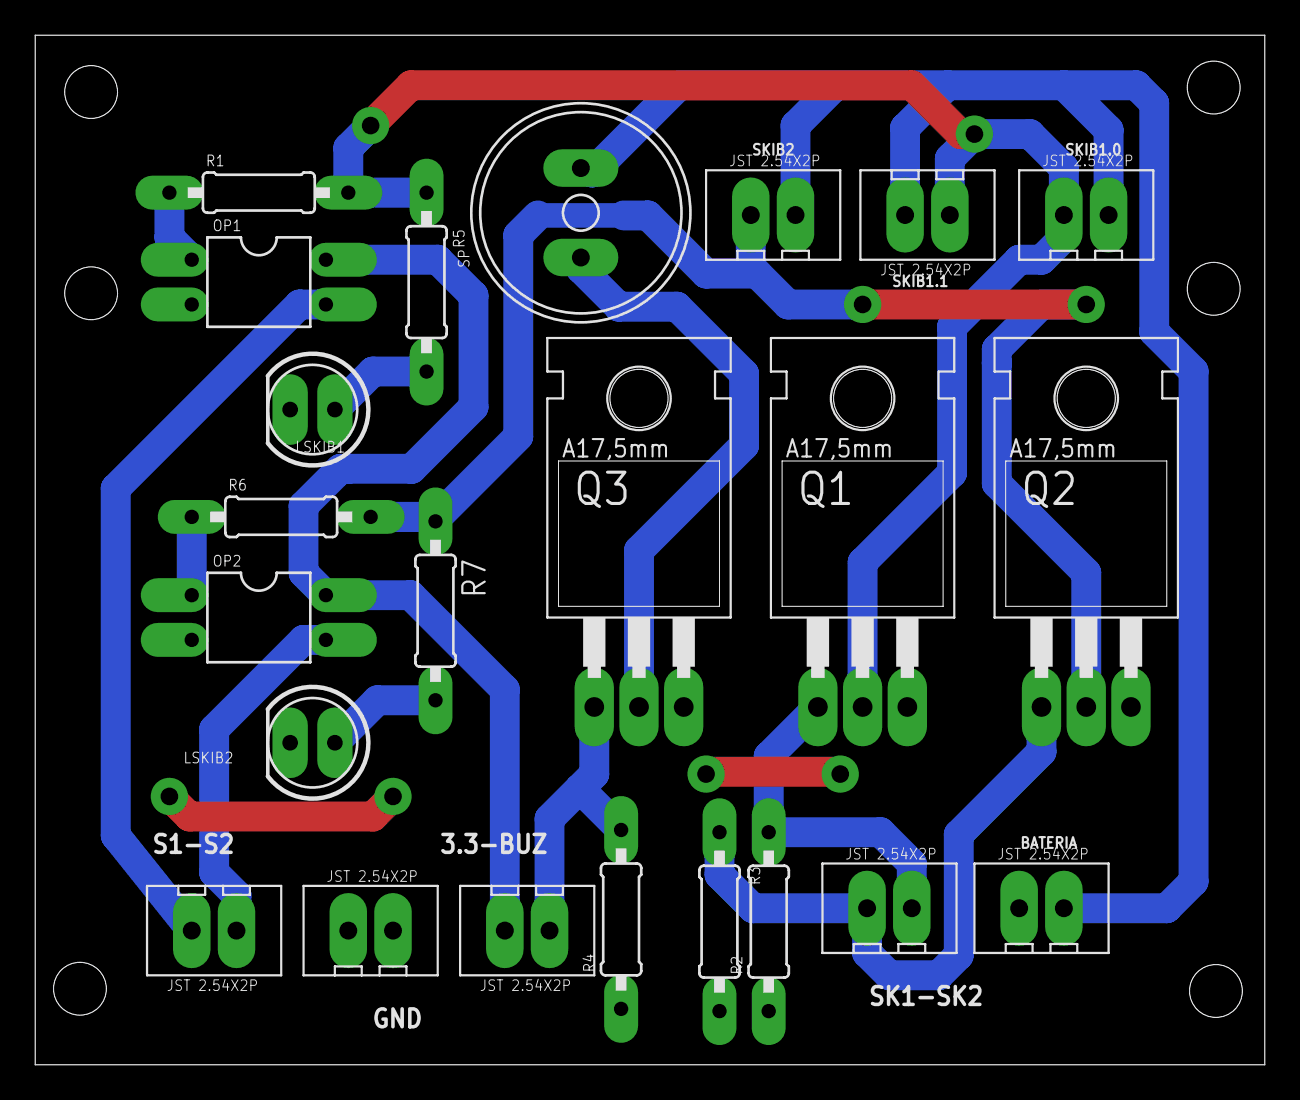
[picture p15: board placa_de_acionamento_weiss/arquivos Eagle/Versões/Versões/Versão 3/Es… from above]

Board: 2 copper layers, 69.8 x 58.5 mm, 23 parts (0 on the bottom side), 15 nets.

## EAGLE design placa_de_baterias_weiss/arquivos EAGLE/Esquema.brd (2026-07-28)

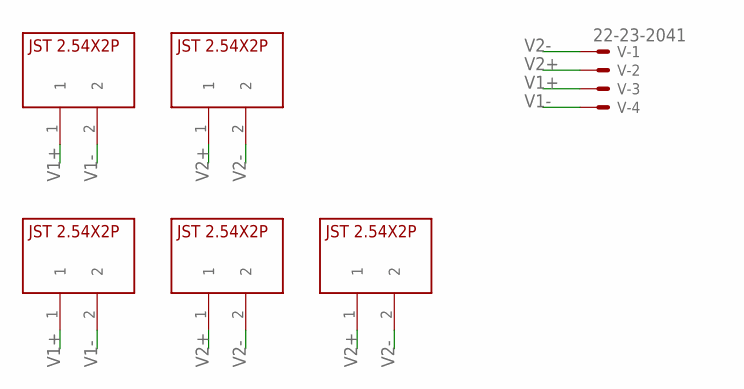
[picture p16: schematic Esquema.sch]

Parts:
U$1, U$2, U$3, U$4, U$5: JST2.54X2P; JST2.54X2P_FOOTPRINT
V: 22-23-2041

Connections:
V1+: U$1.1, U$4.1, V.3
V1-: U$1.2, U$4.2, V.4
V2+: U$2.1, U$3.1, U$5.1, V.2
V2-: U$2.2, U$3.2, U$5.2, V.1


Board: 2 copper layers, 35.6 x 24.4 mm, 6 parts (0 on the bottom side), 4 nets.

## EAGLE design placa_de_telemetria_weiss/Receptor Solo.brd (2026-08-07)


Board: 2 copper layers, 61.9 x 84.3 mm, 7 parts (0 on the bottom side), 10 nets.

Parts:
FUROSDEAPOIOLORA: E22-400T30D; E22-400T30D_FOOTPRINT
LED1, LED2: LED5MM
R1, R2: 330; 0207/10
U$1: ESP32DEVKITV1; ESP32-DEVKITV1
U$2: E22-400T30D; E22-400T30D_FOOTPRINT

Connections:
3.3V: U$1.1, U$2.VCC
AUX: R1.2, U$2.AUX
GND: LED1.K, LED2.K, U$1.2, U$1.29, U$2.GND
GPIO13: R2.2, U$1.28
GPIO19: U$1.10, U$2.M1
GPIO21: U$1.11, U$2.M0
unnamed: LED1.A, R1.1
unnamed: LED2.A, R2.1
RXLORA: U$1.13, U$2.RXD
TXLORA: U$1.12, U$2.TXD

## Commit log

2026-07-05 Change PCB layout image from PNG to JPEG
    Updated PCB layout image format from PNG to JPEG.
2026-07-05 Update PCB layout image format in README
2026-07-15 KiCAD da Placa de iluminação
    Adição dos arquivos do KiCAD da Placa de iluminação
2026-07-15 KiCAD Placa de iluminação
    [Placa_de_Iluminação_Weiss.kicad_pcb, Placa_de_Iluminação_Weiss.kicad_sch, board.kicad_pcb]
2026-07-15 KiCAD Placa de processamento
    [Esquema.kicad_pcb, Esquema.kicad_sch]
2026-07-22 feat: README da placa de processamento do foguete Weiss adicionado
    [Placa_de_Iluminação_Weiss.kicad_pcb, Placa_de_Iluminação_Weiss.kicad_sch]
2026-07-22 Adicionados arquivos da placa de telemetria.
    [Receptor Solo.brd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]
2026-07-26 Atualização da placa de telemetria
    [Receptor Solo.brd, Receptor Solo.sch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]
2026-07-28 Placa de baterias adicionada e convertida para KiCad
    [Esquema.brd, Esquema.kicad_pcb, Esquema.kicad_sch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]
2026-07-30 Placas convertidas com suas respectivas bibliotecas.
    Placa de Acionamento e placa de Baterias.
    [Esquema.brd, Esquema.kicad_pcb, Esquema.kicad_sch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]
2026-07-30 Atualizada a placa de telemetria
    Feedrate XY = 700
    Travel z = 1
    [copper_bottom.gbr, copper_top.gbr, drill_1_16.xln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]
2026-08-04 chore(pcb): adiciona arquivos Gerber e de furação das placas de processamento e acionamento
    [Esquema-B_Cu.gbr, Esquema-B_Mask.gbr, Esquema-B_Paste.gbr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]
2026-08-07 fix(pcb): substitui ESP32 incorreto e adiciona furos de fixação à placa de telemetria
    [Receptor Solo.brd, Receptor Solo.sch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]
2026-08-12 Modelo 3D da placa de processamento (.f3d e .step)
    [Esquema.kicad_pcb, Esquema.kicad_sch]
2026-08-14 fix(telemetria): corrige pinagem da placa de telemetria
    [copper_bottom.gbr, drill_1_16.xln, gerber_job.gbrjob]
2026-08-14 Modelo 3D da placa de processamento
    [Esquema.kicad_pcb, acionamento 3d.step]
2026-08-14 Modelo 3D da placa de acionamento (.step e .f3d)
    [Placa de Acionamento 3D - Weiss.f3d]
2026-08-17 Update(Processamento):Adicionados arquivos Gcode para FR4
    [Esquema-B_Cu.gbr, Esquema-B_Mask.gbr, Esquema-B_Paste.gbr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]

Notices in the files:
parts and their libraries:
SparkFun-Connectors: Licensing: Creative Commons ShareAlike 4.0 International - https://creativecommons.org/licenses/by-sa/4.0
